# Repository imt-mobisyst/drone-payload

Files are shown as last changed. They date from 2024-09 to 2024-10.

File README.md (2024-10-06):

# Drone-Payload
UV projet de P1 en NU / IS, par des FISE 2025 en CI3.

**Membres du groupe** :
- Timothé KOBAK (timothe.kobak@etu.imt-nord-europe.fr)
- Matis SPINELLI (matis.spinelli@etu.imt-nord-europe.fr)
- Arthur MATA (arthur.mata@etu.imt-nord-europe.fr)

**Remarque** : La documentation a été rédigée en partant du principe que toutes les commandes sont effectuées sur un système Ubuntu.

## Tags

Nous avons sauvegardé différentes versions du projet au fil du temps, en fonction des solutions que nous testions.
Il suffit de faire `git checkout <tag>` pour charger le repository d'une ancienne version en local.

- Version **WiFi** (tag: `rpi_wifi`): Serveur utilisant Flask et des fichiers Python et le WiFi pour communiquer avec l'Arduino. C'est une solution simple mais avec une courte portée (moins de 50m a priori).
- Version **PHP** (tag: `php_version`): Page web entièrement en PHP au lieu de Python, fonctionnant avec un serveur *lighttpd*, et communicant en WiFi avec l'Arduino. C'est le prototype le plus ancien du projet. Il est nécessaire de modifier la configuation lighttpd acutelle pour la faire fonctionner.
- Version **1.0** (tag: `parasite_1.0`): Première version fonctionnelle basée sur ZigBee avec une arduino et un module XBee sur le drone et une Raspberry Pi au sol. L'interface web est toujours présente mais tourne en Python via Flask.

## Sommaire de la documentation

Voici une hiérarchie de la documentation présente dans le repository. Les liens sont clicables, et amènent aux fichiers en **markdown** correspondants à la section.

- [Installation PI](./doc/Installation_PI.md) : guide d'installation et de déploiement sur la PI
- [TODO list](./TODO.md) : liste du matériel manquant nécessaire au projet
- [Web](./web/README.md) : code source pour la page web de la PI
- [Scripts](./scripts/README.md) : script bash pour l'automatisation de la tâche déploiement du code sur la PI
- [Design](./Design/README.md) : fichier figma pour le design du logo "PARASITE"
- _Doc générales_
  - [Arduino](./doc/Arduino.md) : installation des fichiers pour Arduino
  - [Payload](./doc/Payload.md) : Carctéristiques du drone et de sa charge utile
  - [SDK](./doc/SDK.md) : Software development kit de DJI pour le drone
    - [MSDK](./doc/SDK/MSDK.md) : Piste du SDK pour mobiles
    - [OSDK](./doc/SDK/OSDK.md) : Piste du SDK embarqué sur le drone

## System Overview

The air sampling system consists of three main components:

1. Drone-mounted payload
2. Ground-level Raspberry Pi
3. User interface device (any web-enabled device)

The **MATRICE 600 PRO** drone serves as the aerial platform for this project.

## Key Features

- **Long-range communication**: Utilizes XBee modules for extended range capabilities
- **High-altitude sampling**: Designed to collect air samples at approximately 120 meters
- **Remote operation**: Controlled via a web-based interface

## Hardware Components

### Payload (Drone-Mounted)

- 1 XBee Module (PRO S2C) with antenna
- 1 Arduino board
- Solenoid valve(s) (1-2 depending on requirements)
- Electrical relay(s) (1-2 matching solenoid valve count)
- Battery pack

### Ground Station

- Raspberry Pi 3(for communication relay)
- XBee Module (PRO S2C) with antenna

### Configuration Setup

- Linux laptop
- Ethernet cable
- Battery Pack

## Communication Architecture

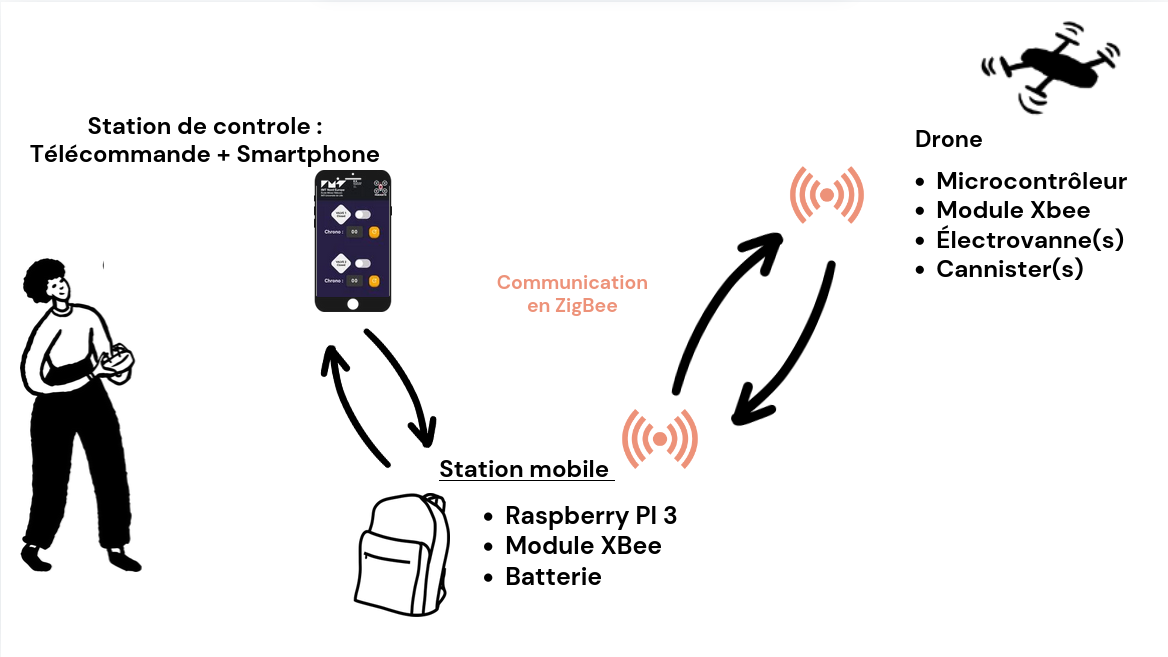
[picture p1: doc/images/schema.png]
Image du schéma fonctionnel général Schéma fonctionnel général


## Advantages

- **Versatility**: Adaptable for various air quality monitoring applications
- **Precision**: Accurate sample collection at specific altitudes
- **Safety**: Enables sampling in hard-to-reach or hazardous areas
- **Real-time control**: Web-based interface allows for immediate adjustments

## Future Enhancements

- Integration of real-time air quality sensors
- Automated flight path programming for systematic sampling

--------------------------------

# Installation 

## 1. Raspberry Pi Setup

To set up the Raspberry Pi, please follow the detailed installation guide in [this file](./doc/Installation_PI.md).

Comme indiqué dans ce fichier, le nombre de vannes utilisé peut être modifié facilement. Il suffit de modifier la valeur `nb_vannes` dans le fichier de configuration [config.json](./web/static/config.json)

## 2. Xbee Configuration 

### Configure XBee Radio:

To properly configure and set up communication between the two XBee modules (one for the Arduino and one for the Raspberry Pi), follow these steps:

1. **Connect the XBee Modules:**
   - Plug both XBee modules into your laptop’s USB ports using XBee USB adapters or a USB-to-serial converter.

2. **Open XCTU Software:**
   - Download and install the [XCTU Software](https://www.digi.com/products/xbee-rf-solutions/xctu-software/xctu) if you haven't already.
   - Open the software and ensure both XBee modules are detected under the "Discover Devices" tab.

3. **Load Configuration Profiles:**
   - You have two configuration profiles provided in the project repository:
     - `profile_arduino.xpro` for the XBee connected to the Arduino.
     - `profile_rpi_coordinator.xpro` for the XBee connected to the Raspberry Pi.
   - To apply these profiles:
     1. Select the XBee module from the device list in XCTU.
     2. Go to the "Profiles" tab and click "Load."
     3. Navigate to the `xbee/arduino` directory, select the appropriate `.xpro` file, and apply the configuration.
     4. Repeat the process for both XBee modules (one for `profile_arduino.xpro` and the other for `profile_rpi_coordinator.xpro`).

4. **Verify XBee Communication:**
   - After applying the configurations, ensure that both XBee modules are set up to communicate with each other. The `profile_rpi_coordinator.xpro` file configures the Raspberry Pi XBee as the communication coordinator, while `profile_arduino.xpro` sets up the Arduino XBee as a remote device.
   - Check the communication settings such as PAN ID, baud rate, and operating channel to ensure they match for both modules.

5. **Connect XBee to Raspberry Pi and Arduino:**
   - **For Arduino:**  
     - Connect the **TX (Transmitter)** pin of the Arduino to the **DIN** pin of the XBee.
     - Connect the **RX (Receiver)** pin of the Arduino to the **DOUT** pin of the XBee.
     - Power the XBee with 3.3V (not 5V) and connect the GND of the Arduino to the GND of the XBee.
   - **For Raspberry Pi:**  
     - Use a USB-to-serial converter to connect the XBee to the Raspberry Pi via USB.
     - Alternatively, connect the **TX/RX** pins of the Raspberry Pi directly to the **DIN/DOUT** pins of the XBee (use a level shifter if required to match voltage levels).

6. **Testing Communication:**
   - After the physical connection and configuration, you can test the communication by sending a basic message from one XBee to the other using XCTU’s console interface. Ensure that the message sent by the Arduino’s XBee is received by the Raspberry Pi’s XBee, confirming successful communication.

## 3. Arduino Setup

To set up the Arduino side of the project, follow these steps:

1. **Install Arduino IDE:**
   - Download and install the [Arduino IDE](https://www.arduino.cc/en/software) if you haven't already.
   
2. **Connect the Arduino:**
   - Connect your Arduino board to your computer via USB.
   
3. **Install Required Libraries:**
   - Open the Arduino IDE and install the necessary libraries for the project:
     - `XBee.h` or any other libraries used in your project.

4. **Upload the Code:**
   - Open the provided Arduino `.ino` file.
   - Select the correct board and port from the "Tools" menu.
   - Upload the sketch to the Arduino.

## 4. Wiring

Here’s how to wire the components together:

### Arduino to XBee:

You can use a diagram like this to visualize the wiring:



### Raspberry Pi to XBee:
- Use a USB-to-serial converter to connect the XBee to the Raspberry Pi via USB.
- Alternatively, connect the **TX/RX** pins of the Raspberry Pi directly to the **DIN/DOUT** pins of the XBee (ensure you use a level shifter to match voltage levels if required).

### Other Connections:
- Add any additional connections (e.g., sensors, LEDs) according to your project needs.

--------------------------------
  
## Anciens repositories :
- https://github.com/ceri-num/alpaga-rambouillet/
- https://github.com/ceri-num/alpaga-ros

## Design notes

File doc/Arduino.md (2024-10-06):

# Programmation de l'Arduino

Le programme de l'Arduino peut être installé via l'IDE Arduino.

[<-- Retour en arrière](./README.md)

Il est également possible de l'installer via l'outil de commande `arduino-cli` si vous disposez de ce dernier.

Sous le dossier `/xbee/arduino/`, on trouve :

- Le programme de l'Arduino, `arduino.ino`.
- Le profil XCTU de la XBee connectée à l'Arduino, `profile_arduino.xpro`.
- (Optionnel) `sketch.yaml`, un fichier de description pour l'outil de commande `arduino-cli`.

## Librairies nécessaires :

- **SoftwareSerial** : Devrait déjà être installé de base avec l'IDE Arduino.
- **XBee-Arduino** : Doit être installé en plus de l'IDE (voir partie suivante).

## Installation avec l'IDE Arduino

- Ouvrer le programme `arduino.ino` situé sous `/xbee/arduino/`.
- Installer la librairie **XBee-Arduino** (seconde entrée de la liste) :

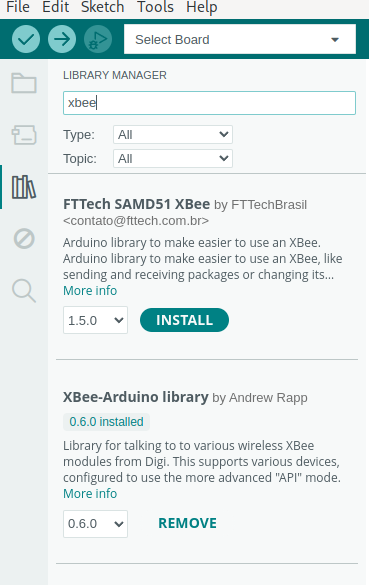
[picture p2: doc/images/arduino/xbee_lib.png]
XBee library


- Sélectionner le port sur lequel la carte est connecté dans l'onglet **Tools**.
- Appuyer sur le bouton **Upload** (flèche en haut à gauche).

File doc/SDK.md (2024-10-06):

# SDK

Intégrer le SDK (Software Development Kit) à notre solution permettrait en théorie de lancer des missions en autonomie simplement avec une appli mobile. Le SDK comporte un OSDK (on-board) et un MSDK (mobile), qui sont capables d'intéragir entre eux.

[<-- Retour en arrière](../README.md)

## Obstacles

Le SDK DJI n'est plus maintenu. https://forum.dji.com/thread-239066-1-1.html.

Nous avons rencontré plusieurs obstacles nous empêchant d'intégrer les SDK au projet, éliminant ainsi les solutions impliquant des missions autonomes du drone.

Veuillez consulter la page des OSDK et MSDK pour connaître plus en détail les obstacles rencontrés :
- [MSDK](./SDK/MSDK.md)
- [OSDK](./SDK/OSDK.md)

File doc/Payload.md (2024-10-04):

# Payload

Documentation sur la charge utile du drone.

[<-- Retour en arrière](../README.md)

## Drone

Caractéristiques techniques du drone :
- **Dimensions** (avec hélices) : 1668 mm x 1518 mm x 759 mm
- **Poids avec les batteries** : 9,6 kg
- **Poids maximum au décollage** : 15,1 kg

On en déduit que l'ensemble **électronique + cannisters + fixations** doit peser **MOINS de 5,5 kg**.

Référence officielle : https://www.dji.com/fr/support/product/matrice600

## Cannister

Voici les caractéristique d'un cannister :
- **Dimensions** : 29.2 x 18.4 cm
- **Volume** : 3 Litres
- **Poids** (avec électrovanne et dépressurisé) : 1.59 kg

**Attention** : La partie "réservoir" du cannister n'est pas une sphère parfaite.

Un modèle 3D approximatif du cannister fait par nous-mêmes est disponibles dans le dossier [CAO](../CAO/v2%20cannister.SLDPRT).

Nous avons envoyé un mail à l'entreprise fabricant les cannisters pour essayer d'obtenir un modèle 3D officiel, mais ils n'en ont pas à disposition malheureusement.

## Dépressurisation

En utilisant une pompe du bâtiment Curie à Bourseul, nous avons réussi à dépressurisé le cannister jusque **90 torr** (0,12 atm). La fuite due à l'électrovanne est d'en moyenne **0,8 torr/min** (1 hectopascal/min), jugée acceptable.

**Note** : 1 atm = 1000 hectopascal = 760 torr

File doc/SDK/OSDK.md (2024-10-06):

# OSDK (OnBoard Software Development Kit)

Tuto de 2020 sur les contrôles de base: https://developer.dji.com/onboard-sdk/documentation/tutorial/basic-control.html

[<-- Retour en arrière](../../README.md)

## Compatibilité

Le OSDK ne peut pas être installé facilement sur une carte Arduino ou un ESP32. En dehors de ROS, seul un STM32 semble possible.
Lien de tutoriel d'installation de 2019 sur différentes plateformes (dont STM32) : https://mylearningspace.imt-nord-europe.fr/.

De même que le OSDK, malgré plusieurs essais, il semble impossible ou très difficile d'utiliser le OSDK sans rien acheter de coûteux, tel que le [Manifold 2C](https://www.dji.com/fr/manifold-2) de DJI.

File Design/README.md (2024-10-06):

# Designs

Ce dossier contient un fichier **.fig**, qui correspond à un design sur **Figma**, et une maquette **.excalidraw** faite avec **Excalidraw**

[<-- Retour en arrière](../README.md)

## Figma

Figma le logiciel en ligne qui a été utilisé pour le design du logo. Si vous souhaitez modifier ce design, vous pouvez vous rendre sur [Figma](https://www.figma.com), et importer le fichier `parasite.fig`.

Le design comporte le logo vectorisé, avec le texte **PARASITE** en dessous. Le nom **PARASITE** peut donc être modifié facilement.

Avec ce design ont été générés :
- [Le logo avec écriture](../web/static/images/parasite.png) (.png)
- [La favicon sans écriture](../web/static/images/favicon.ico) (.ico)
- [Le logo vectorisé sans écriture](../web/static/images/logo.svg) (.svg)

## Excalidraw

Excalidraw est un logiciel en ligne gratuit permettant de faire des maquettes de sites web de manière simple, presque en dessinant à la main.

Le site web actuel est plus avancé que la maquette ne l'était, mais elle peut toujours servir. Vous pouvez vous rendre sur [Excalidraw](https://excalidraw.com/) et importer le fichier `ui.excalidraw`.

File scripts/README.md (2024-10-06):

# Scripts Bash

Ce dossier `scripts` contient des scripts bash pour automatiser certaines tâches nécessaires au développement ou au déploiement.

[<-- Retour en arrière](../README.md)

## Prérequis

Il est nécessaire d'avoir installé `sshpass` pour exécuter certains scripts : `sudo apt install sshpass`.

## Utilisation

Les scripts sont exécutables via un terminal depuis n'importe quel dossier.
Pour exécuter un des scripts, en supposant que vous vous trouvez à la racine du projet, tapez dans un terminal :
```
./scripts/<nomDuScript.sh>
```

**Important** : Si l'exécution échoue, veillez à donner les permissions nécessaires aux fichiers :
```
sudo chmod +x -R ./scripts
```

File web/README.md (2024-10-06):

# Web

Ce dossier contient les fichiers générant la page web de la station et les scripts Python activant les électrovannes.
Auparavant, la page web était générée en PHP. Si vous voulez découvrir la documentation et le code source de la solution en PHP, veuillez remonter au commit taggé `php_version` : `git checkout php_version`.

[<-- Retour en arrière](../README.md)

## Fonctionnement

La page web est générée par un serveur web Flask, qui se lance automatiquement quand la Raspberry Pi boot, via un service configuré dans `/etc/systemd/system/parasiteApp.service`.

## Installation et déploiement

Un fichier de documentation est dédiée [ici](../doc/Installation_PI.md).

## Mise à jour du serveur en production

Si vous avez modifié le code source du dossier `/web`, et que vous voulez mettre à jour le serveur se trouvant sur la Raspberry Pi, vous pouvez exécuter le script dédié à cette tâche (si vous êtes sur IoT IMT Nord Europe) :
```
drone-payload/scripts/update_web.sh
```
Et si vous êtes sur M600_RPI :
```
drone-payload/scripts/update_web.sh -m
```
Enfin, si vous vouhaitez écrire l'adresse IP de la PI à la main :
```
drone-payload/scripts/update_web.sh -a <adresseIP>
```

*Voir la [section sur les scripts](../scripts/README.md)*.

## Mise en route du serveur Flask en debug

Si vous souhaitez voir les **print** des scripts Python, vous pouvez arrêter le service de **systemd**, puis lancer la commande **gunicorn** à la main en ssh (en se trouvant de préférence dans le dossier /home/bot ):
```
sudo systemctl stop parasiteApp.service
sudo gunicorn --chdir /home/bot/flask_app --workers 1 --bind 0.0.0.0:80 wsgi:app
```

Pour lancer le serveur sans utiliser **gunicorn**, en étant par avance connecté à la Raspberry Pi en ssh :
```
flask --app ~/flask-app run --host 0.0.0.0
```

**Attention** : Cette commande n'est pas recommandée pour un serveur en production.

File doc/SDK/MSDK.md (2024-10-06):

# MSDK (Mobile Software Development Kit)

DJI met à disposition un MSDK, qui permet, via une application mobile, de communiquer avec l'OnBoard Computer et son [OSDK](./OSDK.md).
En utilisant le MSDK et le OSDK, cela aurait permis à l'utilisateur au sol de commander le drone via un téléphone ou une tablette.

[<-- Retour en arrière](../../README.md)

## Compatibilité

Depuis 2023, le MSDK n'est plus maintenu ni pour les applis iOS ([source d'information ici](https://sdk-forum.dji.net/hc/en-us/articles/11675868224665-The-announcement-of-iOS-Mobile-SDK)), ni pour Flutter ([source d'information ici](https://sdk-forum.dji.net/hc/en-us/articles/900005842986-Can-you-import-flutter-in-DJI-MSDK-project)).

Voir [ici](https://developer.dji.com/mobile-sdk/documentation/application-development-workflow/workflow-integrate.html) un tuto de 2020 sur l'intégration du MSDK dans une application iOS ou Android.

Malgré plusieurs essais de création d'une application Android simple intégrant le MSDK, nous n'avons pas réussi à obtenir quoi que ce soit de fonctionnel. Nous avons donc abandonné l'idée d'utiliser un MSDK.

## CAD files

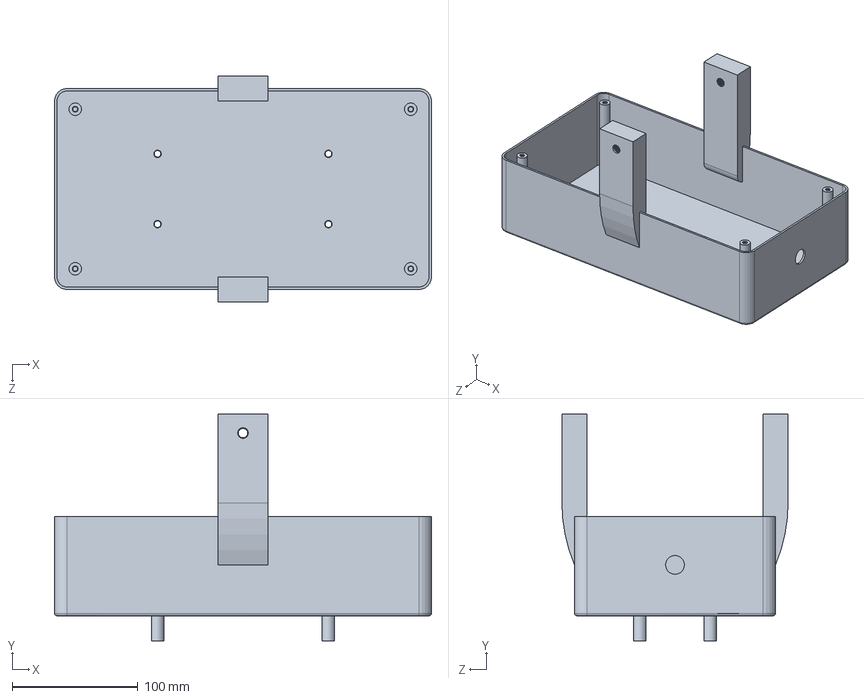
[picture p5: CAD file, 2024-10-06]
CAO/boite.SLDPRT
300.0 x 180.5 x 180.0 mm

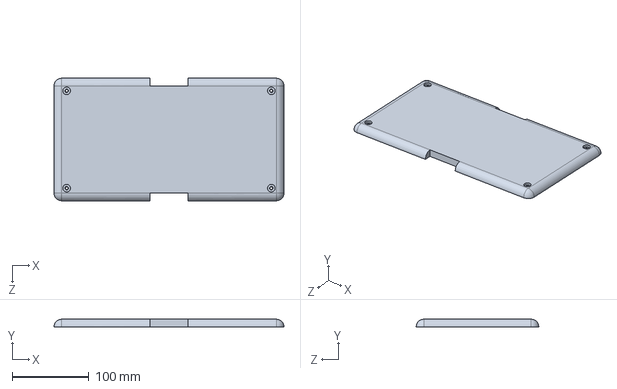
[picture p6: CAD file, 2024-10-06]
CAO/mycouvercle.SLDPRT
300.0 x 10.0 x 160.0 mm

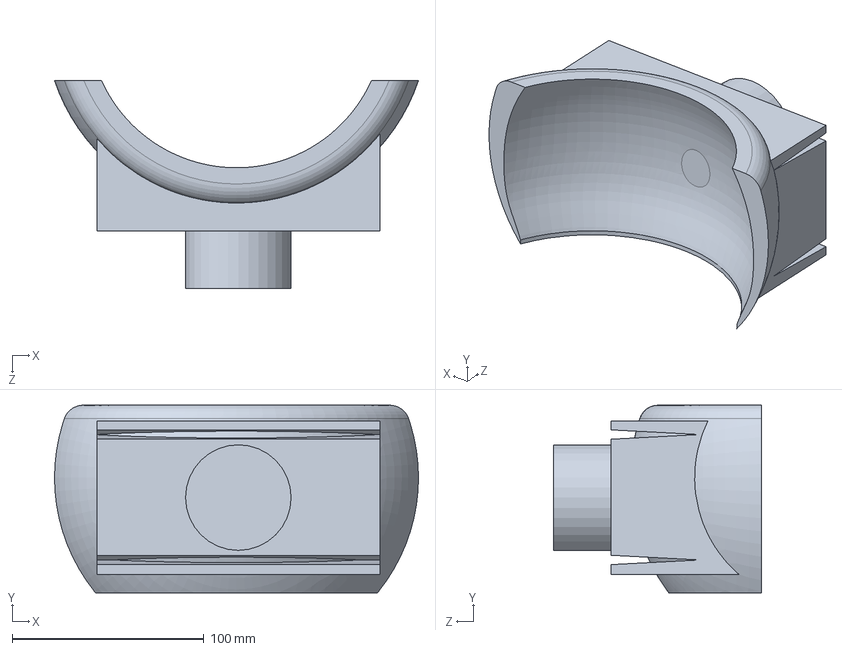
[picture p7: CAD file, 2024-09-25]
CAO/v2 cannister.SLDPRT
189.7 x 97.8 x 108.3 mm

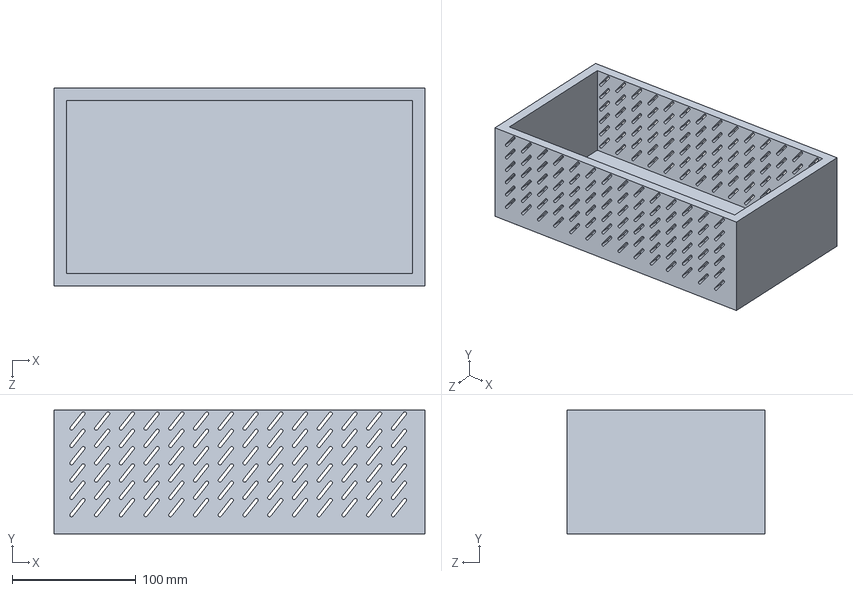
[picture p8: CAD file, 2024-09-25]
CAO/Boites RSPI.SLDPRT
300.0 x 100.0 x 160.0 mm

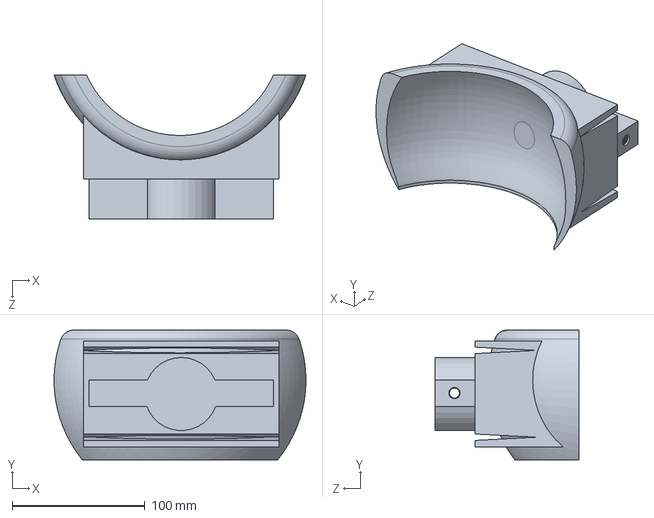
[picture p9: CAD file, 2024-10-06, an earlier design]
CAO/v2 cannister(1).SLDPRT
189.7 x 97.8 x 108.3 mm

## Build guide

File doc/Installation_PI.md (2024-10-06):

# Installation de l'environnement complet sur la PI

[<-- Retour en arrière](../README.md)

## Installation de l'OS sur la Raspberry Pi

```
sudo apt update
sudo apt install rpi-imager
```
Lancer Imager.

Raspberry Pi OS Lite (64 bits) in "Other" :

Image Pi OS OS à installer

Et choisir la carte SD formatée au préalable dans "Storage".
Dans la options, configurer comme ci-dessous :
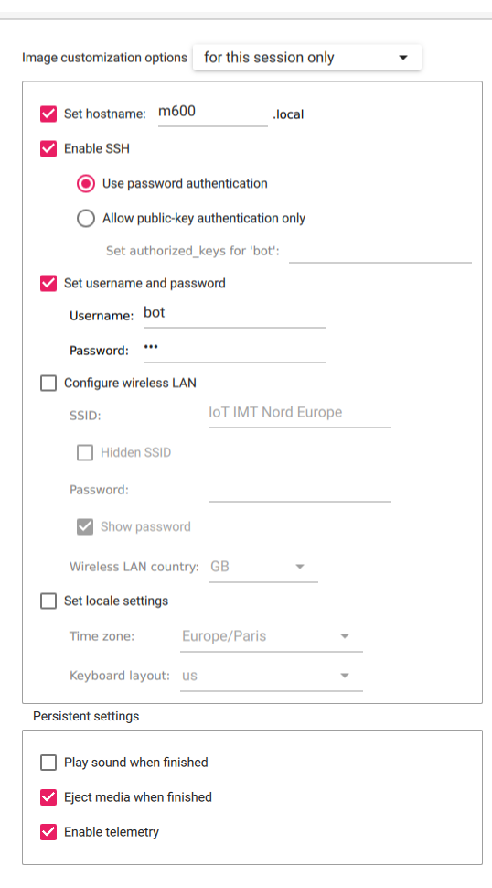
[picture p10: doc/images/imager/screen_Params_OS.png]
Image Parametres Paramètres pour l'OS à installer


Se connecter en ssh : `ssh bot@10.89.2.1` ou `ssh bot@10.89.2.55` en étant connecté à IOT IMT NORD EUROPE. Il faut donc connecter la PI en Ethernet au réseau.
Le mot de passe est celui mis dans les paramètres de Raspberry Imager.

> **Note :**
> Pour se connecter à la Raspberry Pi sur un réseau différent, ou si son adresse IP a changé, vous pouvez utiliser `arp-scan -lg` pour essayer de la trouver.  

### RaspAP

Les commandes suivantes sont à effectuer en ssh sur la pi

Source d'infos : https://raspap.com/#quick

```
sudo apt update
sudo apt full-upgrade
sudo reboot
```

```
sudo raspi-config
```

Dans le menu qui apparaît :
- Dans `Localisation Options` > `Locale` : sélectonner `fr_FR.UTF-8 UTF-8` puis `en_GB.UTF-8`.
- Dans `Localisation options` > `Timezone` : sélectionner `Europe` puis `Paris`.
- Dans `Localisation Options` > `WLAN Country` : sélectionner `FR France`.

```
curl -sL https://install.raspap.com | bash
```

Dans les questions qui suivent :
- Laisser le chemin `/var/www/html` par défaut.
- Accepter `Complete installation with these values?`.
- Dire non à toutes les questions suivantes.
- Accepter de faire un reboot.

(Sur la Raspberry Pi) Éditer le fichier `/lib/systemd/system/hostapd.service` :

```
[Unit]
Description=Access point and authentication server for Wi-Fi and Ethernet
Documentation=man:hostapd(8)
After=network.target
ConditionFileNotEmpty=/etc/hostapd/hostapd.conf

[Service]
Type=forking
PIDFile=/run/hostapd.pid
Restart=on-failure
RestartSec=2
Environment=DAEMON_CONF=/etc/hostapd/hostapd.conf
EnvironmentFile=-/etc/default/hostapd
ExecStart=/usr/sbin/hostapd -B -P /run/hostapd.pid $DAEMON_OPTS ${DAEMON_CONF}
ExecStartPre=/bin/sleep 1                                                        # Ajouter cette ligne 

[Install]
WantedBy=multi-user.target
```

Puis redémarrer la Pi.

Vous pouvez vous rendre sur la page de RaspAP en tapant l'adresse IP de la PI sur le réseau IOT IMT NORD EUROPE en tant qu'url :
- **username** : `admin`
- **password** : `secret`

Sur cette page, rendez-vous dans le menu **Hotspot**, et remplissez les champs comme les mages ci-dessous :
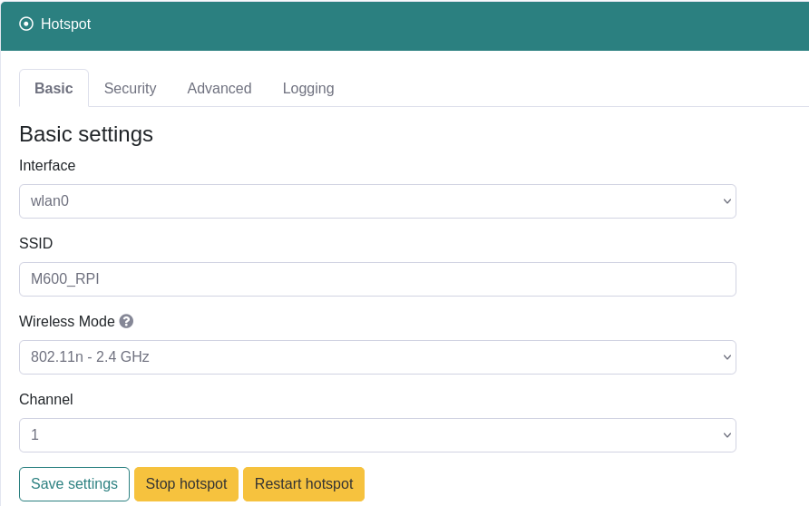
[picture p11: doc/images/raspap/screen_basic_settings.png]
Image Basic settings Basic settings de RaspAP

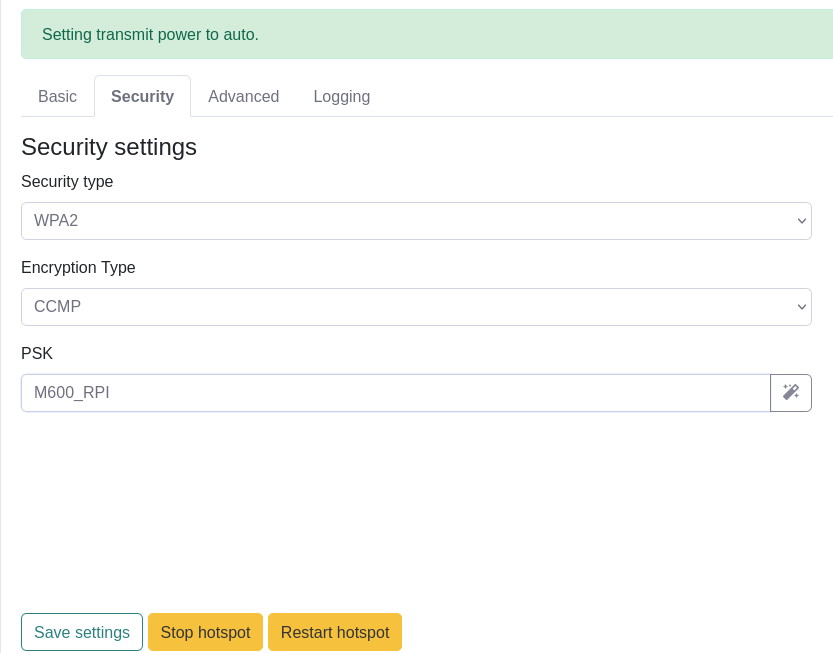
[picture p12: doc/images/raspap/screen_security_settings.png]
Image Security settings Security settings de RaspAP


Appuyer sur `Save settings` puis `Restart Hotspot`.

Le réseau **M600_RPI** devrait apparaître quelques secondes plus tard. Le mot de passe est celui configuré dans les *security settings*, dans le champ **PSK**.

```
sudo nano /etc/lighttpd/lighttpd.conf
```
Puis changer le port `80` en port `8080`, et restart le service `sudo systemctl restart lighttpd.service`

Dorénavant, l'url pour se rendre sur la page de raspap est : `http://<adresseIP>:8080`.

## Installation de l'environnement de production

Créer le dossier qui contiendra les fichiers de l'appli web :
`mkdir /home/bot/flask_app`

## Serveur en production

Vous pouvez vérifier les commandes suivantes dans ce tuto si vous le désirez : https://sysadmin.cyklodev.com/deployer-une-application-flask/.

### Config du service :

Installation d'une dépendance pour faire tourner le serveur :
```
sudo apt install gunicorn
```

Mise en place du service dans *systemd* :
```
sudo nano /etc/systemd/system/parasiteApp.service
```

Coller le contenu suivant dans ce fichier :
```
[Unit]
Description=Gunicorn Flask Parasite App 
After=network.target

[Service]
User=bot
Group=bot
WorkingDirectory=/home/bot/flask_app
ExecStart=sudo gunicorn --chdir /home/bot/flask_app --workers 1 --bind 0.0.0.0:80 wsgi:app

[Install]
WantedBy=multi-user.target
```

### Config du DNS

Éditer le fichier `/etc/dnsmask.d/090_raspap.conf` et ajouter les lignes suivantes à la fin du fichier :

```
port=53
listen-address=127.0.0.1,10.3.141.1
interface=wlan0

domain=station.local
address=/station.local/10.3.141.1
```

### Config du serveur

Installation de flask :
```
sudo apt install python3-flask
```

Installation de pip :
```
sudo apt install python3-pip
```

Installation de digi-xbee :
```
sudo apt install python3-serial && \
    pip download digi-xbee && \
    unzip digi_xbee-1.5.0-py3-none-any.whl && \
    sudo mv digi /usr/local/lib/python3.11/dist-packages/
```

Lancer le service gunicorn :
```
sudo systemctl enable parasiteApp.service
sudo systemctl start parasiteApp.service
```

Et en notant les adresses IP, bien veiller à ce que l'url soit en "http" et non en "https".

## Dépendances côté développeur :

**Attention**, les commandes suivantes sont à effectuer son le pc du développeur en local :

Faites un git clone du repository à l'endroit de votre choix sur votre pc.

### Configuration des scripts

Dans le fichier de configuration [config.json](../web/static/config.json), préciser le nombre de vannes utilisées (par défaut sur 2).

Si vous modifiez cette valeur du fichier de configuration, il faut mettre à jour le code sur la PI et redémarrer le service (voir la section suivante).

Puis, trouver l'adresse MAC de la PI grâce à `arp-scan` :
```
sudo apt install arp-scan
```

En étant connecté à IoT IMT Nord Europe, tapez :
```
sudo arp-scan -lg
```

L'adresse MAC de la PI se trouve très probablement à la ligne comportant le nom `Raspberry Pi Trading Ltd`.
Écrivez cette adresse dans la variable `IP_IOT=` en haut du fichier [find_pi.sh](../scripts/update_web.sh).
Puis faites de même en étant connecté au réseau de la PI, dans la variable `IP_RPI=`.

Puis uploader le code source sur la PI en exécutant le script correspondant dans votre repository :
```
cd drone-payload
sudo chmod +x -R ./scripts
```

Installation de sshpass pour l'exécution des scripts :
```
sudo apt install sshpass
```

Enfin, en étant connecté à IoT IMT Nord Europe, lancer le script :
```
./scripts/update_web.sh
```
Si vous êtes connecté à un autre réseau, ou que vous voulez préciser l'adresse manuellement, veuillez consulter l'aide [ici](../scripts/README.md) ou faire `./scripts/update_web.sh -h`.

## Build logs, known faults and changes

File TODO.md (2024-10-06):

# Project TODO List

This document outlines the remaining tasks that need to be completed before the project can be considered finished. 

[<-- Retour en arrière](./README.md)

### 
- [ ] **Payload Structure**: Design and print the 3D payload structure for the cannister and the electronics
- [ ] **Purchase one battery**: Battery for the RPI station
- [ ] **Box**: Box for the mobile RPI station 

### Equipment to Duplicate for Safety

| Component Name | Minimal Quantity (In Use) | Spare parts | Total Quantity |
| --- | --- | --- | --- |
| Xbee Card | 2 | 2 | 4 |
| Xbee shield | 2 | 2 | 4 |
| Battery | 1 | 1 | 2 |
| SD Card RPI Flashed | 1 | 1 | 2 |
| USB C --> Battery RPI | 1 | 1 | 2 |
| USB A --> USB Mini B (XBee RPI) | 1 | 1 | 2 |

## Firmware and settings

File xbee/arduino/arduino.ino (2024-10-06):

#include <SoftwareSerial.h>
#include <XBee.h>

#define RX_PIN 2
#define TX_PIN 3

// Valves are 1 indexed
#define VALVE_PIN_OFFSET 6
#define V1_PIN 7
#define V2_PIN 8
/* ------------- If other valves are needed : -------------
#define V3_PIN 9
#define V4_PIN 10
#define V5_PIN 11
#define V6_PIN 12
#define V7_PIN 13
*/

#define GET_VALVE_PIN(_p) (_p + VALVE_PIN_OFFSET)
#define GET_VALVE_PIN_CHAR(_p) (GET_VALVE_PIN((uint8_t)_p - 48))

/*
 * Global variables
 */
uint8_t confirm_payload[] = { 'C' };
uint8_t valves_payloads[][2] = {
  { '1', 'C' },
  { '2', 'C' },
  /* ------------- If other valves are needed : -------------
  { '3', 'C' },
  { '4', 'C' },
  { '5', 'C' },
  { '6', 'C' },
  { '7', 'C' },
*/
};

XBeeAddress64 addr64 = XBeeAddress64(0x0013a200, 0x41bf6a51);
SoftwareSerial xbeeSerial(RX_PIN, TX_PIN);
XBeeWithCallbacks xbee = XBeeWithCallbacks();
ZBTxRequest tx = ZBTxRequest(addr64, confirm_payload, sizeof(confirm_payload));

void zbResponseCallback(ZBRxResponse &rx, uintptr_t other_data_p) {
  xbee.getResponse().getZBRxResponse(rx);
  uint8_t *data_p = rx.getData();

  if (*data_p == 'X') {  // XBee connection test
    tx.setPayload(confirm_payload, 1);
  } else {
    uint8_t valve_pin = GET_VALVE_PIN_CHAR(data_p[1]);
    uint8_t valve_index = valve_pin - VALVE_PIN_OFFSET - 1;

    if (data_p[0] == 'O') {
      // Open valve
      digitalWrite(valve_pin, HIGH);
      valves_payloads[valve_index][1] = 'O';
      tx.setPayload(valves_payloads[valve_index], 2);
    } else if (data_p[0] == 'C') {
      // Close valve
      digitalWrite(valve_pin, LOW);
      valves_payloads[valve_index][1] = 'C';
      tx.setPayload(valves_payloads[valve_index], 2);
    }
  }

  xbee.send(tx);
}

void errorCallback(uint8_t err, uintptr_t func_data_p) {
  Serial.print("Error code : ");
  Serial.println(err, 10);
}

/*
 * Setup
 */
void setup() {
  Serial.begin(9600);
  xbeeSerial.begin(9600);
  xbeeSerial.listen();

  xbee.onPacketError(errorCallback, 0);
  xbee.onZBRxResponse(zbResponseCallback, 0);

  pinMode(V1_PIN, OUTPUT);
  pinMode(V2_PIN, OUTPUT);
  /* ------------- If other valves are needed : -------------
  pinMode(V3_PIN, OUTPUT);
  pinMode(V4_PIN, OUTPUT);
  pinMode(V5_PIN, OUTPUT);
  pinMode(V6_PIN, OUTPUT);
  pinMode(V7_PIN, OUTPUT);
  */

  xbee.begin(xbeeSerial);
}

void loop() {
  xbee.loop();
}

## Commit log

2024-09-18 complete responsive timer
2024-09-25 Premier commit apres reparation du SSH
    [Boites RSPI.SLDPRT, v2 cannister.SLDPRT]
2024-09-27 Timers fix
2024-09-28 Ajout de la RPI au install.md
2024-09-30 Arduino XBee with interrupts
2024-09-30 Arduino XBee
2024-09-30 Arduino and RPI XBee Config
2024-10-04 Arduino Config
2024-10-04 Ajout LED Indicateur Connexion
2024-10-04 Connexion Device RPI
2024-10-04 Connection to Arduino
2024-10-06 Fichiers CCAO SLDPART
    [boite.SLDPRT, mycouvercle.SLDPRT, v2 cannister(1).SLDPRT]
